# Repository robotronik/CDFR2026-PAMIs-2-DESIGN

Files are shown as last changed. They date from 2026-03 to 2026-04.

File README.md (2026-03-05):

# 🤖 PAMI - Coupe de France de Robotique 2026 - Carte Électronique (PCB)




Bienvenue sur le dépôt dédié à la conception de la carte électronique (PCB) des **PAMI** (Petits Actionneurs Mobiles Intelligents) de notre équipe pour la Coupe de France de Robotique 2026.

Ce dépôt centralise les schémas, le routage, les fichiers de fabrication (Gerber) et la nomenclature (BOM) de la carte mère du robot.

---

## ⚙️ Spécifications Matérielles (Hardware)

### ⚡ Architecture Électronique & Puissance
La carte mère est conçue autour d'un microcontrôleur ESP32 et intègre toute la distribution de puissance, le contrôle moteur et les interfaces capteurs/IHM.

* **Cerveau :** Microcontrôleur ESP32 (Modèle précis à déterminer).
* **Programmation & Debug :** Port USB-C intégré à la carte.
* **Alimentation Générale :** Entrée Batterie avec coupure de sécurité matérielle via un **Bouton d'Arrêt d'Urgence (BAU)**.
* **Drivers Moteurs DC :** 2x TB67H420FTG (Contrôle indépendant des moteurs gauche/droit).

### 🏎️ Motorisation & Cinématique (Rappel de la cible)
* **Moteurs :** 2x CHW-4632-370 ABHL 6V (Moteurs CC à balais avec réducteur à vis sans fin).
* **Rapport de réduction :** 1:32 (Renvoi d'angle à 90° - 185 RPM à vide).
* **Vitesse de croisière estimée :** ~27 cm/s (avec des roues de 40 mm).
* **Couple de décrochage (Stall Torque) :** > 2.9 Kg.cm par moteur.
* **Odométrie :** Encodeurs magnétiques à effet Hall (Quadratrure Phase A/B), offrant ~352 tics par tour de roue.

### 📡 Capteurs & Actionneurs Auxiliaires
* **Évitement (Adversaires/Obstacles) :** Interface pour capteur LIDAR.
* **Actionneurs secondaires :** Connectique pour 2x Servomoteurs.

### 🕹️ Interface Homme-Machine (IHM) intégrée
* **Affichage Équipe :** 1x LED RGB.
* **Indicateurs de Statut (Batterie, Erreurs, etc.) :** 4x LEDs standards.
* **Configuration (Changement couleur équipe) :** 1x Bouton poussoir utilisateur.

---

## 📂 Architecture du Dépôt

```text
📦 PAMI-PCB-2026
 ┣ 📂 hardware/               # Projet KiCad (Schémas et Routage)
 ┣ 📂 fabrication/            # Fichiers générés pour l'usinage/assemblage (Générés en fin de projet)
 ┣ 📂 docs/                   # Documentation technique
 ┗ 📜 README.md

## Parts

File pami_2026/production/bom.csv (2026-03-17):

Designator | Footprint | Quantity | Value | LCSC Part #
BAU1, C_BATT1, SW_TEAM1 | PinHeader_1x02_P2.54mm_Vertical | 3 | Conn_01x02_Pin | C32713268
C1, C14, C16, C6, C9 | 0603 | 5 | 100nF | C1591
C10 | 0805 | 1 | 22uF | C602037
C11 | 0603 | 1 | 1uF | C15849
C12 | 0603 | 1 | 0.1uF | C1591
C13, C15 | Panasonic_F | 2 | 47uF | C128464
C19 | CAP_EEETC1C101V | 1 | 100uF | C2163886
C2, C3 | 0805 | 2 | 10µF | C15850
C4, C5, C7, C8 | 0805 | 4 | 22µF | C602037
D1 | D_SOD-123 | 1 | D,Zener,IEC | C41408110
D5 | D_SOD-123 | 1 | D_Schottky | C908229
DC_A1, DC_B1 | PinHeader_1x06_P2.54mm_Vertical | 2 | Conn_01x06 | C37208
F1 | 1206 | 1 | Fuse | C48783168
L1, L2 | L_Wurth_WE-LQSH-4020 | 2 | 4.7µH | C6364810
Q1, Q2 | SOT-223 | 2 | PMOS | C49066897
R1 | 0603 | 1 | 100K | C2906980
R10, R21, R3 | 0603 | 3 | 1K | C22548
R11 | 0603 | 1 | 2K | C105576
R12, R13, R15, R16, R17, R18, R20, R6, R7, R8, R9 | 0603 | 11 | 10K | C98220
R14, R19 | 0603 | 2 | 24K | C2930081
R2 | 0603 | 1 | 470 | C4045076
R4 | 0603 | 1 | 2.2K | C114662
R5 | 0603 | 1 | 20K | C105575
SERVO_1, SERVO_2, TEAM_RGB1 | PinHeader_1x03_P2.54mm_Vertical | 3 | Conn_01x03_Pin | C32713269
SW1 | PinHeader_1x02_P2.54mm_Vertical | 1 | SW_Reed | C32713268
SWPUSHBOOT1, SWPUSHRESET1 | Push_SMD_6.2x6.2mm | 2 | SMD_6.2x6.2mm_h7.0mm | C967701
S_3.3V1, S_5V1, S_BATT1, S_ESP1 | 0603 | 4 | LED | C965799
U1 | ESP32-WROOM-32E | 1 | ESP32-WROOM-E | C701343
U2 | TSOT-23-6 | 1 | AP63205WU | C2071056
U3, U6 | Texas_HTSOP-8-1EP_3.9x4.9mm_P1.27mm_EP2.95x4.9mm_Mask2.4x3.1mm_ThermalVias | 2 | DRV8871DDA | C701805
U5 | TSOT-23-6 | 1 | AP63203WU | C780769
UART1, US1 | PinHeader_1x04_P2.54mm_Vertical | 2 | Conn_01x04_Pin | C42431808

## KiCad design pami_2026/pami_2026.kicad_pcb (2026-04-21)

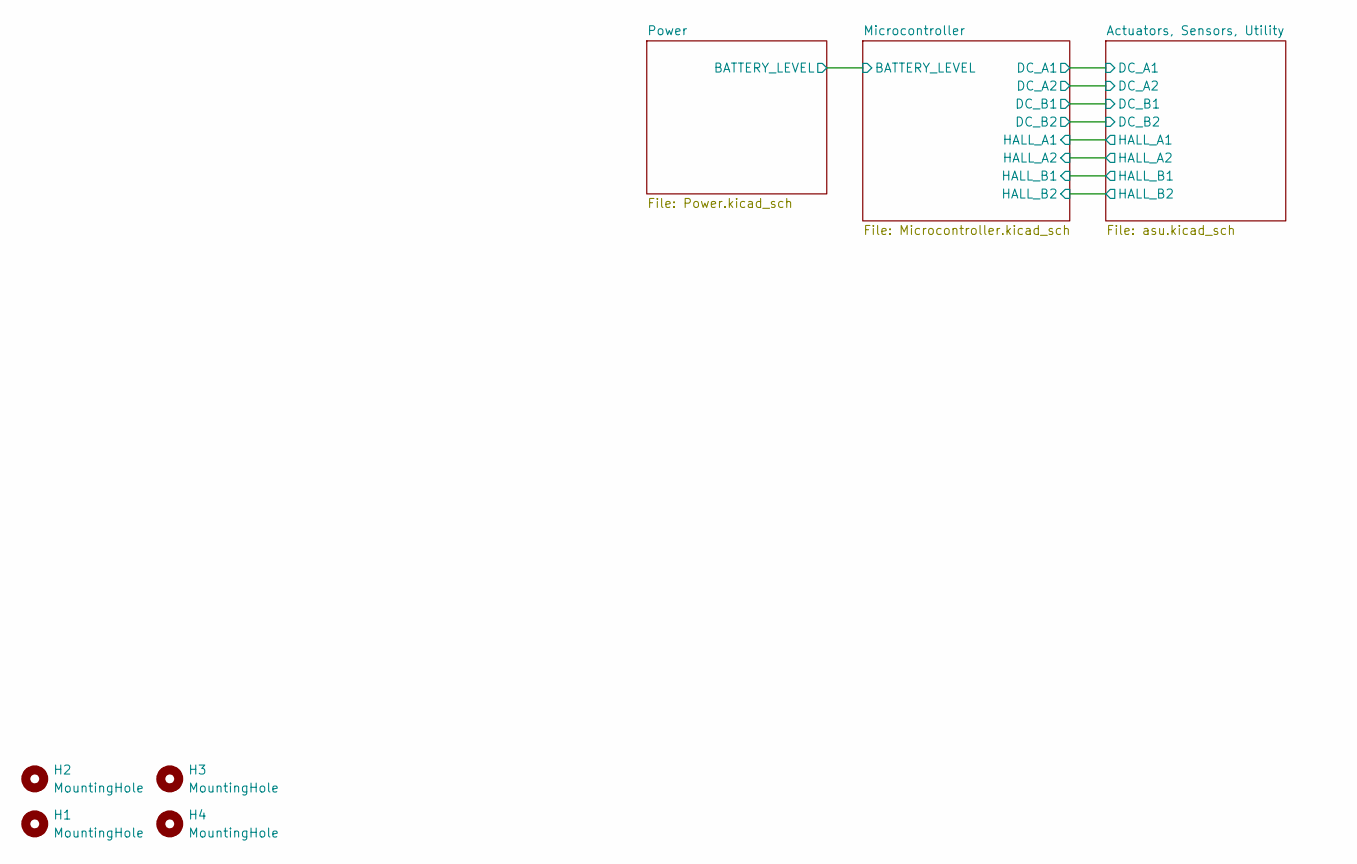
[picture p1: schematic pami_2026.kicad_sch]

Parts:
H1, H2, H3, H4: MountingHole; MountingHole_2.2mm_M2_ISO7380_Pad

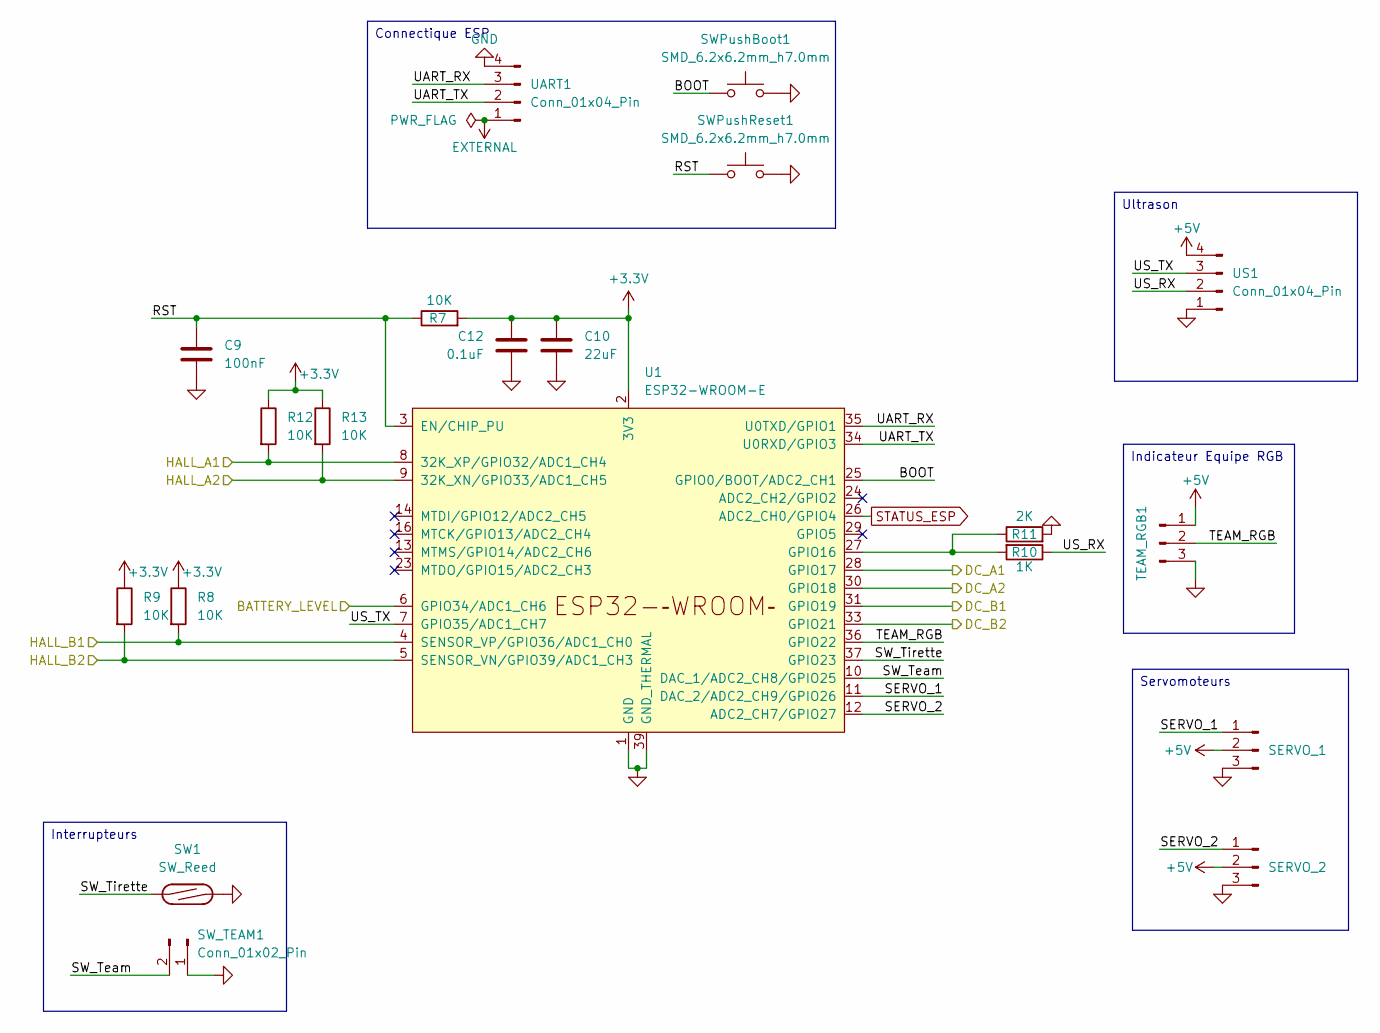
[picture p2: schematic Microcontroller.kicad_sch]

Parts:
C9: 100nF; C_0603_1608Metric; LCSC C1591
C10: 22uF; C_0805_2012Metric; LCSC C602037
C12: 0.1uF; C_0603_1608Metric; LCSC C1591
R7, R8, R9, R12, R13: 10K; R_0603_1608Metric; LCSC C98220
R10: 1K; R_0603_1608Metric; LCSC C22548
R11: 2K; R_0603_1608Metric; LCSC C105576
SERVO_1, SERVO_2: Conn_01x03_Pin; PinHeader_1x03_P2.54mm_Vertical; LCSC C32713269
SW1: SW_Reed; PinHeader_1x02_P2.54mm_Vertical; LCSC C32713268
SWPushBoot1: SMD_6.2x6.2mm_h7.0mm; Push_SMD_6.2x6.2mm; Mfg Part# 679-2384-2-ND; LCSC C967701
SWPushReset1: SMD_6.2x6.2mm_h7.0mm; Push_SMD_6.2x6.2mm; Mfg Part# 679-2384-2-ND; LCSC C967701
SW_TEAM1: Conn_01x02_Pin; PinHeader_1x02_P2.54mm_Vertical; LCSC C32713268
TEAM_RGB1: Conn_01x03_Pin; PinHeader_1x03_P2.54mm_Vertical; LCSC C32713269
U1: ESP32-WROOM-E; ESP32-WROOM-32E; LCSC C701343
UART1: Conn_01x04_Pin; PinHeader_1x04_P2.54mm_Vertical; LCSC C42431808
US1: Conn_01x04_Pin; PinHeader_1x04_P2.54mm_Vertical; LCSC C42431808

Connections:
+3.3V: C10.1, C12.1, R7.2, R8.1, R9.1, R12.1, R13.1, U1.2 (3V3); also elsewhere on the board
+5V: SERVO_1.2, SERVO_2.2, TEAM_RGB1.1, US1.4; also elsewhere on the board
/Actuators, Sensors, Utility/DC_A1: U1.28 (GPIO17); also elsewhere on the board
/Actuators, Sensors, Utility/DC_A2: U1.30 (GPIO18); also elsewhere on the board
/Actuators, Sensors, Utility/DC_B1: U1.31 (GPIO19); also elsewhere on the board
/Actuators, Sensors, Utility/DC_B2: U1.33 (GPIO21); also elsewhere on the board
/Actuators, Sensors, Utility/HALL_A1: R12.2, U1.8 (32K_XP/GPIO32/ADC1_CH4); also elsewhere on the board
/Actuators, Sensors, Utility/HALL_A2: R13.2, U1.9 (32K_XN/GPIO33/ADC1_CH5); also elsewhere on the board
/Actuators, Sensors, Utility/HALL_B1: R8.2, U1.4 (SENSOR_VP/GPIO36/ADC1_CH0); also elsewhere on the board
/Actuators, Sensors, Utility/HALL_B2: R9.2, U1.5 (SENSOR_VN/GPIO39/ADC1_CH3); also elsewhere on the board
/Microcontroller/BATTERY_LEVEL: U1.6 (GPIO34/ADC1_CH6); also elsewhere on the board
/Microcontroller/BOOT: SWPushBoot1.1, U1.25 (GPIO0/BOOT/ADC2_CH1)
/Microcontroller/RST: C9.1, R7.1, SWPushReset1.1, U1.3 (EN/CHIP_PU)
/Microcontroller/SERVO_1: SERVO_1.1, U1.11 (DAC_2/ADC2_CH9/GPIO26)
/Microcontroller/SERVO_2: SERVO_2.1, U1.12 (ADC2_CH7/GPIO27)
/Microcontroller/SW_Team: SW_TEAM1.2, U1.10 (DAC_1/ADC2_CH8/GPIO25)
/Microcontroller/SW_Tirette: SW1.1, U1.37 (GPIO23)
/Microcontroller/TEAM_RGB: TEAM_RGB1.2, U1.36 (GPIO22)
/Microcontroller/UART_RX: U1.35 (U0TXD/GPIO1), UART1.3
/Microcontroller/UART_TX: U1.34 (U0RXD/GPIO3), UART1.2
/Microcontroller/US_RX: R10.1, US1.2
/Microcontroller/US_TX: U1.7 (GPIO35/ADC1_CH7), US1.3
EXTERNAL: UART1.1; also elsewhere on the board
GND: C9.2, C10.2, C12.2, R11.2, SERVO_1.3, SERVO_2.3, SW1.2, SWPushBoot1.2, SWPushReset1.2, SW_TEAM1.1, TEAM_RGB1.3, U1.1 (GND), U1.15 (GND), U1.38 (GND), U1.39 (GND_THERMAL), UART1.4, US1.1; also elsewhere on the board
unnamed: R10.2, R11.1, U1.27 (GPIO16)
STATUS_ESP: U1.26 (ADC2_CH0/GPIO4); also elsewhere on the board

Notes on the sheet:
Interrupteurs
Indicateur Equipe RGB
Connectique ESP
Servomoteurs
Ultrason

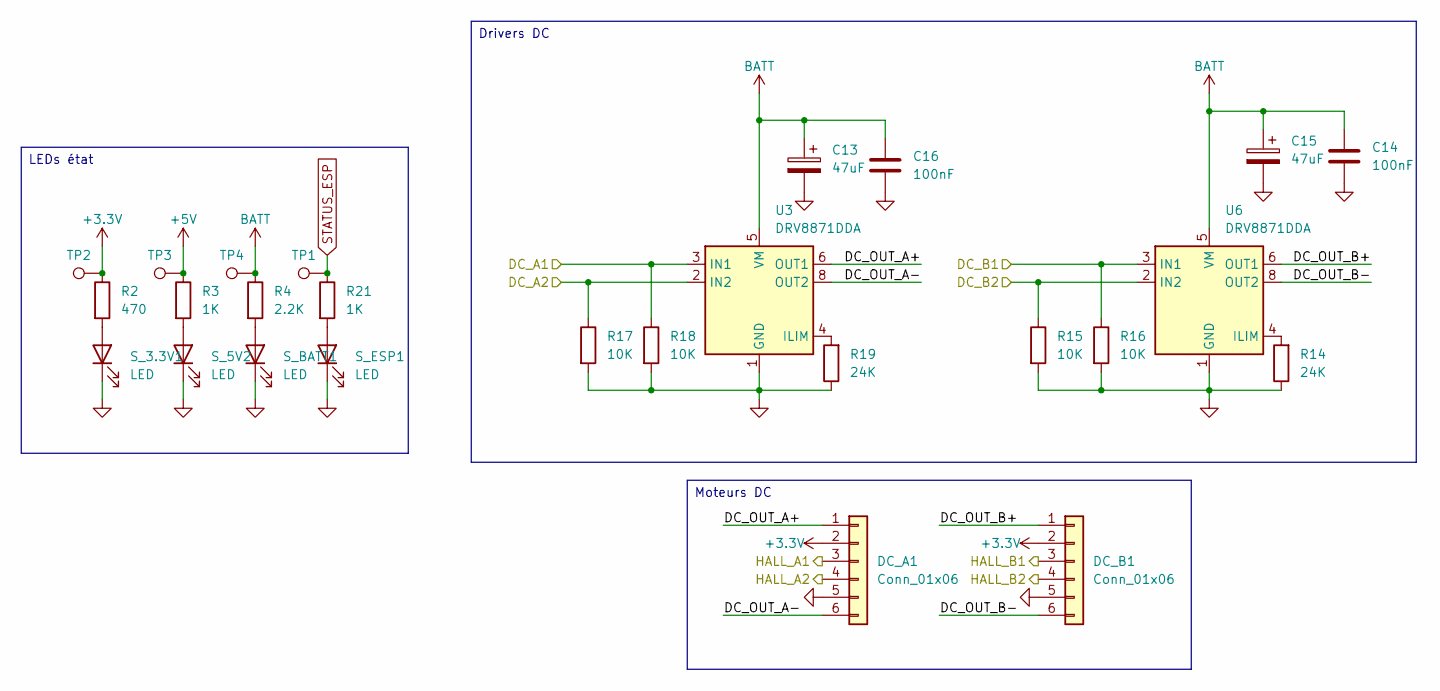
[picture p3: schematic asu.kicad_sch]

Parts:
C13, C15: 47uF; Panasonic_F; LCSC C128464
C14, C16: 100nF; C_0603_1608Metric; LCSC C1591
DC_A1: Conn_01x06; PinHeader_1x06_P2.54mm_Vertical; LCSC C37208
DC_B1: Conn_01x06; PinHeader_1x06_P2.54mm_Vertical; LCSC C37208
R2: 470; R_0603_1608Metric; LCSC C4045076
R3, R21: 1K; R_0603_1608Metric; LCSC C22548
R4: 2.2K; R_0603_1608Metric; LCSC C114662
R14, R19: 24K; R_0603_1608Metric; LCSC C2930081
R15, R16, R17, R18: 10K; R_0603_1608Metric; LCSC C98220
S_3.3V1, S_5V2: LED; LED_0603_1608Metric; LCSC C965799
S_BATT1: LED; LED_0603_1608Metric; LCSC C965799
S_ESP1: LED; LED_0603_1608Metric; LCSC C965799
TP1, TP2, TP3, TP4: TestPoint; TestPoint_Pad_1.0x1.0mm
U3, U6: DRV8871DDA; Texas_HTSOP-8-1EP_3.9x4.9mm_P1.27mm_EP2.95x4.9mm_Mask2.4x3.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; LCSC C701805

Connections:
+3.3V: DC_A1.2, DC_B1.2, R2.1, TP2.1; also elsewhere on the board
+5V: R3.1, TP3.1; also elsewhere on the board
/Actuators, Sensors, Utility/DC_A1: R18.1, U3.3 (IN1); also elsewhere on the board
/Actuators, Sensors, Utility/DC_A2: R17.1, U3.2 (IN2); also elsewhere on the board
/Actuators, Sensors, Utility/DC_B1: R16.1, U6.3 (IN1); also elsewhere on the board
/Actuators, Sensors, Utility/DC_B2: R15.1, U6.2 (IN2); also elsewhere on the board
/Actuators, Sensors, Utility/DC_OUT_A+: DC_A1.1, U3.6 (OUT1)
/Actuators, Sensors, Utility/DC_OUT_A-: DC_A1.6, U3.8 (OUT2)
/Actuators, Sensors, Utility/DC_OUT_B+: DC_B1.1, U6.6 (OUT1)
/Actuators, Sensors, Utility/DC_OUT_B-: DC_B1.6, U6.8 (OUT2)
/Actuators, Sensors, Utility/HALL_A1: DC_A1.3; also elsewhere on the board
/Actuators, Sensors, Utility/HALL_A2: DC_A1.4; also elsewhere on the board
/Actuators, Sensors, Utility/HALL_B1: DC_B1.3; also elsewhere on the board
/Actuators, Sensors, Utility/HALL_B2: DC_B1.4; also elsewhere on the board
BATT: C13.1, C14.1, C15.1, C16.1, R4.1, TP4.1, U3.5 (VM), U6.5 (VM); also elsewhere on the board
GND: C13.2, C14.2, C15.2, C16.2, DC_A1.5, DC_B1.5, R14.1, R15.2, R16.2, R17.2, R18.2, R19.1, S_3.3V1.1 (K), S_5V2.1 (K), S_BATT1.1 (K), S_ESP1.1 (K), U3.1 (GND), U3.7 (GND), U3.9 (GND), U6.1 (GND), U6.7 (GND), U6.9 (GND); also elsewhere on the board
unnamed: R2.2, S_3.3V1.2 (A)
unnamed: R3.2, S_5V2.2 (A)
unnamed: R4.2, S_BATT1.2 (A)
unnamed: R21.2, S_ESP1.2 (A)
unnamed: R19.2, U3.4 (ILIM)
unnamed: R14.2, U6.4 (ILIM)
STATUS_ESP: R21.1, TP1.1; also elsewhere on the board

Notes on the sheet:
Moteurs DC
LEDs état
Drivers DC

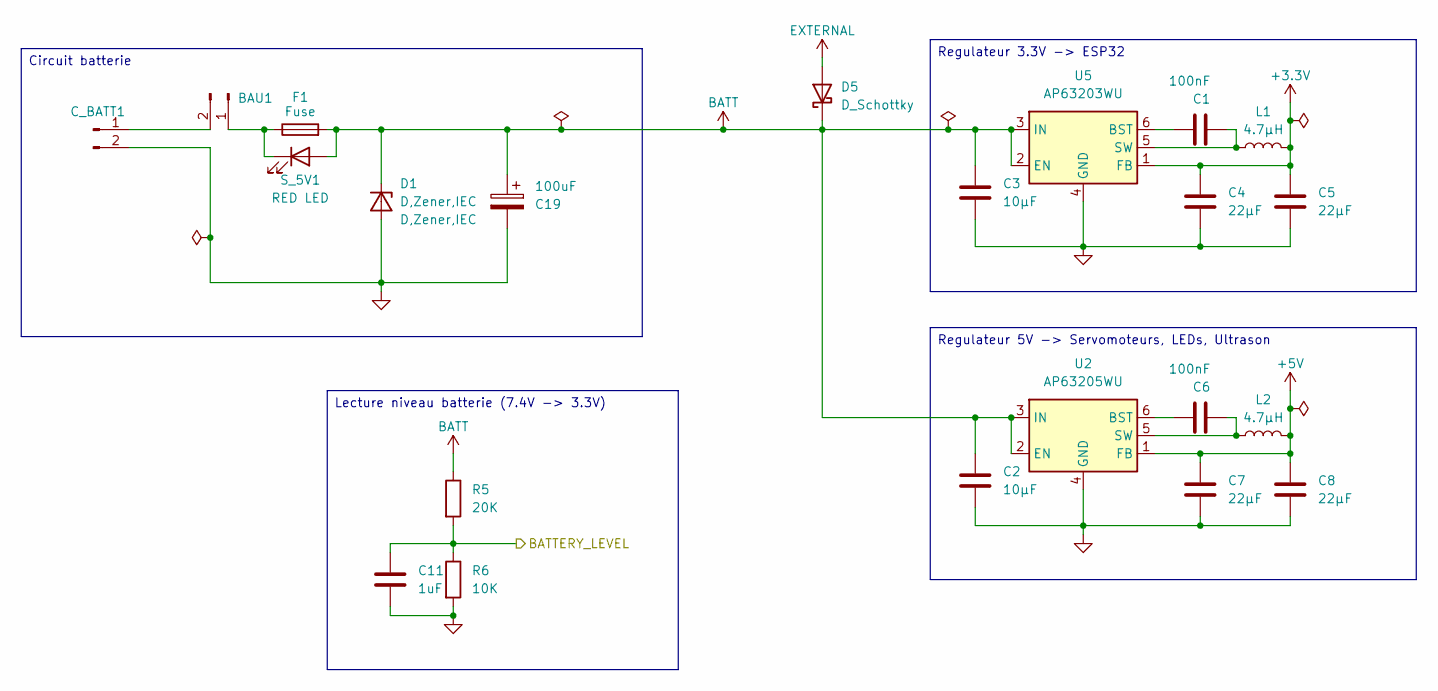
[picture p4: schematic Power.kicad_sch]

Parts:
BAU1: Conn_01x02_Pin; PinHeader_1x02_P2.54mm_Vertical; LCSC C32713268
C1, C6: 100nF; C_0603_1608Metric; LCSC C1591
C2, C3: 10µF; C_0805_2012Metric; LCSC C15850
C4, C5, C7, C8: 22µF; C_0805_2012Metric; LCSC C602037
C11: 1uF; C_0603_1608Metric; LCSC C15849
C19: 100uF; CAP_EEETC1C101V; LCSC C2163886
C_BATT1: Conn_01x02_Pin; PinHeader_1x02_P2.54mm_Vertical; LCSC C32713268
D1: D,Zener,IEC; D_SOD-123; LCSC C41408110
D5: D_Schottky; D_SOD-123; LCSC C908229
F1: Fuse; Fuse_1206_3216Metric; LCSC C48783168
L1, L2: 4.7µH; L_Wurth_WE-LQSH-4020; LCSC C6364810
R5: 20K; R_0603_1608Metric; LCSC C105575
R6: 10K; R_0603_1608Metric; LCSC C98220
S_5V1: RED LED; LED_0603_1608Metric; LCSC C965799
U2: AP63205WU; TSOT-23-6; LCSC C2071056
U5: AP63203WU; TSOT-23-6; LCSC C780769

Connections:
+3.3V: C4.1, C5.1, L1.2, U5.1 (FB); also elsewhere on the board
+5V: C7.1, C8.1, L2.2, U2.1 (FB); also elsewhere on the board
/Microcontroller/BATTERY_LEVEL: C11.1, R5.2, R6.1; also elsewhere on the board
BATT: C2.1, C3.1, C19.1, D1.1 (K-), D5.1 (K), F1.2, R5.1, S_5V1.2 (A), U2.2 (EN), U2.3 (IN), U5.2 (EN), U5.3 (IN); also elsewhere on the board
EXTERNAL: D5.2 (A); also elsewhere on the board
GND: C2.2, C3.2, C4.2, C5.2, C7.2, C8.2, C11.2, C19.2, C_BATT1.2, D1.2 (A+), R6.2, U2.4 (GND), U5.4 (GND); also elsewhere on the board
unnamed: BAU1.1, F1.1, S_5V1.1 (K)
unnamed: BAU1.2, C_BATT1.1
unnamed: C6.1, U2.6 (BST)
unnamed: C6.2, L2.1, U2.5 (SW)
unnamed: C1.1, U5.6 (BST)
unnamed: C1.2, L1.1, U5.5 (SW)

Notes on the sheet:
Regulateur 5V -> Servomoteurs, LEDs, Ultrason
Circuit batterie
Regulateur 3.3V -> ESP32
Lecture niveau batterie (7.4V -> 3.3V)

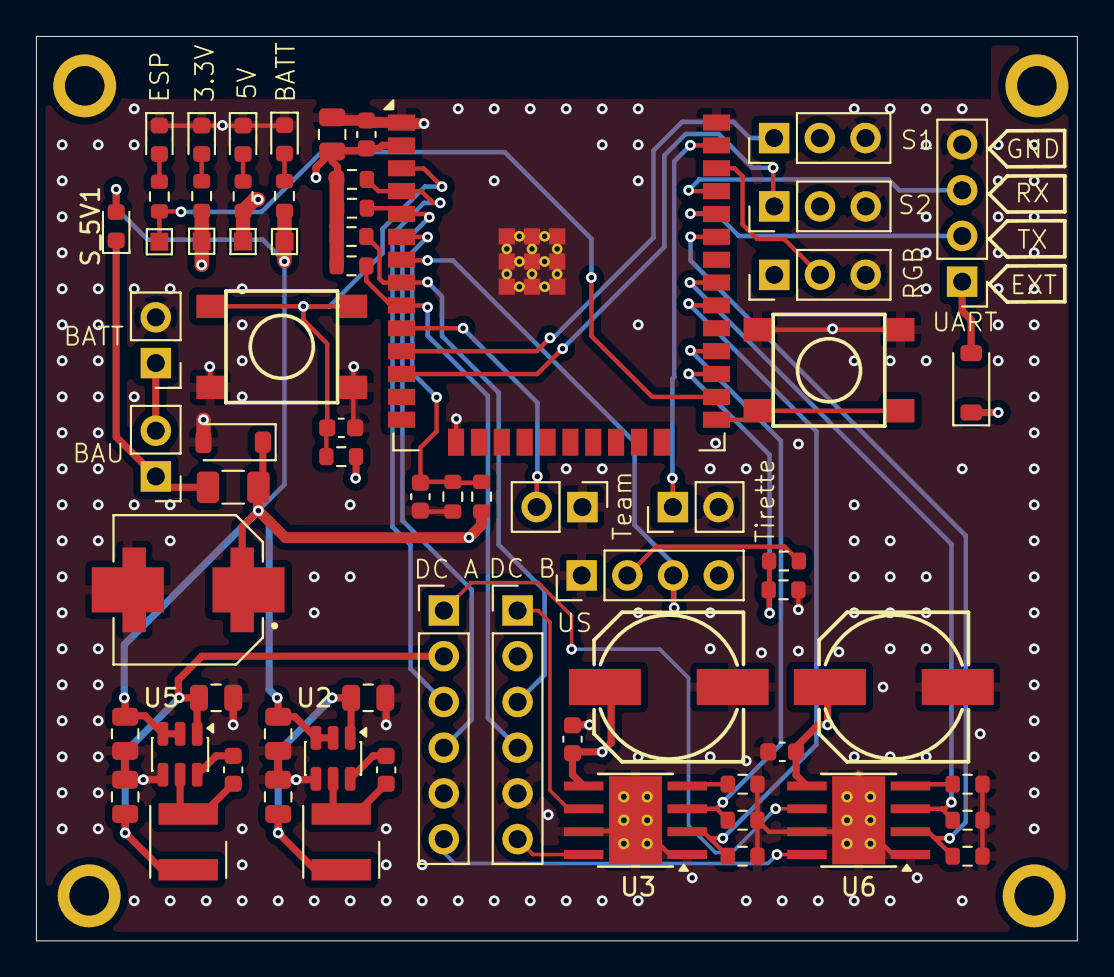
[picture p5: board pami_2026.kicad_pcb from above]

Board: 4 copper layers, 57.8 x 50.2 mm, 72 parts (0 on the bottom side), 43 nets.

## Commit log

2026-03-10 voltage regulators
    [Microcontroller.kicad_sch, Power.kicad_sch, pami_2026.kicad_sch]
2026-03-10 Battery circuit and DC Driver
    [Power.kicad_sch]
2026-03-10 WIP alim stage
    [Power.kicad_sch]
2026-03-11 WIP actuators
    [Microcontroller.kicad_sch, Power.kicad_sch, asu.kicad_sch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]
2026-03-11 WIP USB programmer
    [Microcontroller.kicad_sch, Power.kicad_sch, asu.kicad_sch]
2026-03-12 Change DC drivers, apply datasheet recommendations, add big capacitor, remove USB programmer for simple connector
    [Microcontroller.kicad_sch, Power.kicad_sch, asu.kicad_sch]
2026-03-12 Hall pull up
    [Microcontroller.kicad_sch, Power.kicad_sch]
2026-03-12 Ultrason, empreintes et petites corrections
    [Microcontroller.kicad_sch, Power.kicad_sch, asu.kicad_sch]
2026-03-12 Fix polarity protection and change drivers
    [Power.kicad_sch]
2026-03-12 update caps
    [Power.kicad_sch]
2026-03-12 make erc happier
    [Microcontroller.kicad_sch, Power.kicad_sch]
2026-03-13 Fix: ERC is Happy - proper footprints - Feat: add multiplexer for external power
    [Microcontroller.kicad_sch, Power.kicad_sch, asu.kicad_sch]
2026-03-13 fix footprints
    [Power.kicad_sch]
2026-03-13 fix strapping pin
    [Microcontroller.kicad_sch]
2026-03-14 FEAT : Routing
    [Microcontroller.kicad_sch, Power.kicad_sch, asu.kicad_sch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]
2026-03-14 FEAT : Via Stitching
    [pami_2026.kicad_pcb]
2026-03-16 Feat: mounting holes, indications, fix capa polarity
    [Power.kicad_sch, pami_2026.kicad_pcb, pami_2026.kicad_sch]
2026-03-17 Feat: BOM LCSC + big plan de masse
    [Microcontroller.kicad_sch, Power.kicad_sch, asu.kicad_sch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]
2026-04-20 Fixes and updates to v2
    [Microcontroller.kicad_sch, Power.kicad_sch, asu.kicad_sch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]
2026-04-21 Fix servo pinout
    [Microcontroller.kicad_sch, pami_2026.kicad_pcb]
